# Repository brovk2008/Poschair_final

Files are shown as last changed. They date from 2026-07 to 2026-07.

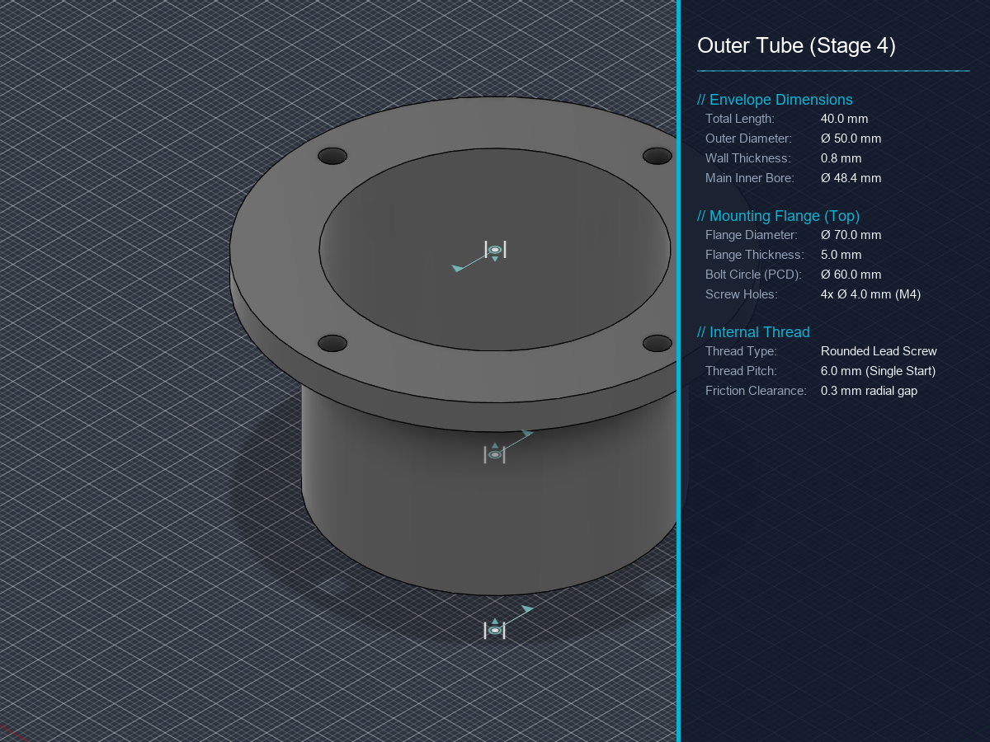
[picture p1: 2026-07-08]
new actuator (tube actuator)/dimentions/OuterTube_dimensions.png

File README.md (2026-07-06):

# PosChair

AI-assisted posture correction hardware for chairs, built around a browser vision loop, BLE control, and a 2x3 paraspinal actuator grid.





PosChair tracks posture locally with MediaPipe Pose, converts posture deviation into six linear actuator targets, and sends those commands to an ESP32 DevKit V1 over Bluetooth Low Energy. The v3 hardware uses DC geared motors, BTS7960 H-bridge drivers, and custom worm-rack actuators that move foam pads up to 100mm.

## Current Version

**V3 motorized actuator architecture**

- 6 custom worm-rack actuators in a 2x3 paraspinal grid
- 6 BTS7960 H-bridge motor drivers
- ESP32 DevKit V1 BLE peripheral using NimBLE-Arduino
- Web Bluetooth dashboard for Chrome/Edge
- Local-only camera posture analysis with MediaPipe WASM
- FastAPI backend for profile, calibration, and session history

## Architecture

```text
Camera
  -> MediaPipe Pose running in browser
  -> Posture analyzer
  -> Velocity-aware decision engine
  -> Web Bluetooth command packet
  -> ESP32 DevKit V1
  -> 6x BTS7960 H-bridges
  -> DC geared motors
  -> Worm-rack actuators
  -> Foam pads on paraspinal muscles
```

## Hardware Layout

```text
        LEFT COLUMN      RIGHT COLUMN

ROW 1:  [UL - M0]       [UR - M1]    Upper thoracic / shoulder
ROW 2:  [ML - M2]       [MR - M3]    Mid lumbar
ROW 3:  [LL - M4]       [LR - M5]    Lower lumbar / pelvis
```

The center spine line is intentionally left open. The modules press into paraspinal muscle areas on either side of the spine.

## Features

- **Position-based actuation:** command values are 0-100, mapping to 0-100mm of linear pad travel.
- **Continuous correction:** forward lean and lateral lean are mapped proportionally instead of using only fixed thresholds.
- **Velocity awareness:** fast posture deterioration increases actuator response before the user fully slouches.
- **Confidence gating:** low-confidence pose frames hold the previous motor target to avoid mechanical jitter.
- **Startup homing:** every boot retracts the actuators to the 0mm home position before BLE control begins.
- **BLE failsafe:** if command packets stop for more than 2 seconds, all modules retract to 0mm.
- **Privacy-first vision:** raw camera frames stay in the browser.

## Repository Structure

```text
firmware/
  poschair_firmware/      Main ESP32 DevKit BLE + motor control firmware
  poschair_motor_test/    Motor calibration and wiring test sketch

app/
  frontend/               React + Vite dashboard with Web Bluetooth
  backend/                FastAPI backend for profiles, calibration, sessions
  docker-compose.yml      Local full-stack development environment

docs/
  hardware_wiring.md      BTS7960, ESP32 DevKit, and actuator wiring reference
  protocol.md             BLE packet protocol reference

website/                  Public Next.js marketing/documentation site
```

## Quick Start

### 1. Wire the Hardware

Connect each BTS7960 driver to the ESP32 DevKit V1 using the pin map in [docs/hardware_wiring.md](docs/hardware_wiring.md). Use a separate motor power rail sized for your motors and keep all grounds common.

Do not power the DC motors from the ESP32 or USB.

### 2. Calibrate Motor Speed

Flash the motor test sketch:

```text
firmware/poschair_motor_test/poschair_motor_test.ino
```

Measure how far each actuator moves during the 2000ms extension test.

```text
MOTOR_SPEED_MM_PER_MS = measured_mm / 2000.0
```

Update the value in:

```text
firmware/poschair_firmware/config.h
```

### 3. Flash Main Firmware

Open the main sketch in Arduino IDE 2.x:

```text
firmware/poschair_firmware/poschair_firmware.ino
```

Recommended Arduino settings:

- Board: `ESP32 Dev Module`
- Flash Size: `4MB`
- CPU Frequency: `240MHz`
- Library: `NimBLE-Arduino`

### 4. Run the App

```bash
cd app
docker-compose up --build
```

Open [http://localhost:5173](http://localhost:5173) in Chrome or Edge.

Web Bluetooth is required, so Safari/iOS and Firefox are not supported for hardware control.

## BLE Protocol

Device name:

```text
POSCHAIR_001
```

Command packet, app to ESP32:

```text
[0]   0xA5
[1]   UL position 0-100
[2]   UR position 0-100
[3]   ML position 0-100
[4]   MR position 0-100
[5]   LL position 0-100
[6]   LR position 0-100
[7]   XOR checksum of bytes 0-6
```

Status packet, ESP32 to app:

```text
[0]   0x5A
[1]   flags: bit0=ok, bit1=failsafe, bit2=homed, bit3=moving
[2]   battery mV high byte
[3]   battery mV low byte
[4-9] current module positions, UL through LR
```

See [docs/protocol.md](docs/protocol.md) for UUIDs and test packets.

## Development Commands

Frontend dashboard:

```bash
cd app/frontend
npm run build
```

Website:

```bash
cd website
npm run build
```

Full local stack:

```bash
cd app
docker-compose up --build
```

## Safety Notes

This project controls physical hardware. Use conservative travel limits, soft foam padding, current-appropriate wiring, and a separate motor power supply. Test one module at a time before wearing or leaning against the full chair attachment.

The firmware clamps commanded travel to 100mm and retracts on BLE timeout, but mechanical end stops and careful power design are still required.

## Status

V3 implementation is active on ESP32 DevKit V1. The app and website builds pass locally. Firmware should be compiled and flashed through Arduino IDE after installing NimBLE-Arduino and selecting the ESP32 board package.

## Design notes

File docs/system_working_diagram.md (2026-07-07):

# PosChair V3 System Working Diagram

This document shows the full PosChair V3 system from every user, sensor, software, BLE, firmware, driver, motor, actuator, and feedback input to every output.

## 1. End-to-End System Flow

```mermaid
flowchart LR
  User["User sitting on chair"]
  Camera["Browser camera input"]
  Light["Lighting / camera angle"]
  Browser["Chrome or Edge dashboard"]
  Pose["MediaPipe Pose WASM"]
  Analyzer["Posture Analyzer"]
  Decision["V3 Decision Engine"]
  BLEClient["Web Bluetooth Manager"]
  BLEAir["BLE radio link"]
  ESP32["ESP32 DevKit V1 firmware"]
  MotorCtrl["MotorController timed-position model"]
  Drivers["6x BTS7960 H-bridge drivers"]
  Motors["6x DC geared motors"]
  WormRack["6x worm-rack actuators"]
  FoamPads["6x foam pads"]
  Back["User paraspinal muscles"]
  Status["BLE status notify"]
  UI["Dashboard UI"]
  Backend["FastAPI backend"]
  DB["PostgreSQL database"]

  User --> Camera
  Light --> Camera
  Camera --> Browser
  Browser --> Pose
  Pose --> Analyzer
  Analyzer --> Decision
  Decision --> BLEClient
  BLEClient --> BLEAir
  BLEAir --> ESP32
  ESP32 --> MotorCtrl
  MotorCtrl --> Drivers
  Drivers --> Motors
  Motors --> WormRack
  WormRack --> FoamPads
  FoamPads --> Back
  Back --> User

  ESP32 --> Status
  Status --> BLEAir
  BLEAir --> BLEClient
  BLEClient --> UI
  Analyzer --> UI
  Decision --> UI
  UI --> Backend
  Backend --> DB
  DB --> Backend
  Backend --> UI
```

## 1A. Physical Wiring Connection Diagram

```mermaid
flowchart LR
  ESP["ESP32 DevKit V1"]
  GND["Common ground bus"]
  V33["ESP32 3.3V"]
  EN["GPIO5 shared enable"]
  ADC["GPIO34 battery ADC"]
  BATP["12V battery positive"]
  BATN["12V battery negative"]
  Fuse["Fuse / switch"]
  Divider["100k / 100k voltage divider"]

  subgraph Drivers["BTS7960 drivers"]
    D0["M0 UL driver"]
    D1["M1 UR driver"]
    D2["M2 ML driver"]
    D3["M3 MR driver"]
    D4["M4 LL driver"]
    D5["M5 LR driver"]
  end

  subgraph Motors["DC motors and actuators"]
    M0["M0 upper-left motor"]
    M1["M1 upper-right motor"]
    M2["M2 mid-left motor"]
    M3["M3 mid-right motor"]
    M4["M4 lower-left motor"]
    M5["M5 lower-right motor"]
  end

  ESP -->|"GPIO25 RPWM, GPIO26 LPWM"| D0
  ESP -->|"GPIO27 RPWM, GPIO16 LPWM"| D1
  ESP -->|"GPIO14 RPWM, GPIO13 LPWM"| D2
  ESP -->|"GPIO17 RPWM, GPIO18 LPWM"| D3
  ESP -->|"GPIO21 RPWM, GPIO22 LPWM"| D4
  ESP -->|"GPIO23 RPWM, GPIO19 LPWM"| D5

  EN -->|"R_EN + L_EN"| D0
  EN -->|"R_EN + L_EN"| D1
  EN -->|"R_EN + L_EN"| D2
  EN -->|"R_EN + L_EN"| D3
  EN -->|"R_EN + L_EN"| D4
  EN -->|"R_EN + L_EN"| D5

  V33 -->|"VCC logic"| D0
  V33 -->|"VCC logic"| D1
  V33 -->|"VCC logic"| D2
  V33 -->|"VCC logic"| D3
  V33 -->|"VCC logic"| D4
  V33 -->|"VCC logic"| D5

  BATP --> Fuse
  Fuse -->|"B+"| D0
  Fuse -->|"B+"| D1
  Fuse -->|"B+"| D2
  Fuse -->|"B+"| D3
  Fuse -->|"B+"| D4
  Fuse -->|"B+"| D5

  BATN --> GND
  ESP -->|"GND"| GND
  GND -->|"GND and B-"| D0
  GND -->|"GND and B-"| D1
  GND -->|"GND and B-"| D2
  GND -->|"GND and B-"| D3
  GND -->|"GND and B-"| D4
  GND -->|"GND and B-"| D5

  D0 -->|"M+ / M-"| M0
  D1 -->|"M+ / M-"| M1
  D2 -->|"M+ / M-"| M2
  D3 -->|"M+ / M-"| M3
  D4 -->|"M+ / M-"| M4
  D5 -->|"M+ / M-"| M5

  BATP --> Divider
  GND --> Divider
  Divider --> ADC
```

## 1B. One Driver Wiring Template

```mermaid
flowchart TB
  ESP["ESP32 DevKit"]
  Driver["One BTS7960 driver"]
  Motor["One DC geared motor"]
  Battery["12V motor supply"]
  Ground["Common ground"]

  ESP -->|"Assigned RPWM GPIO"| Driver
  ESP -->|"Assigned LPWM GPIO"| Driver
  ESP -->|"GPIO5 to R_EN"| Driver
  ESP -->|"GPIO5 to L_EN"| Driver
  ESP -->|"3.3V to VCC"| Driver
  ESP -->|"GND"| Ground
  Ground -->|"GND and B-"| Driver
  Battery -->|"B+"| Driver
  Driver -->|"M+"| Motor
  Driver -->|"M-"| Motor
```

## 2. Inputs and Outputs

```mermaid
flowchart TB
  subgraph Inputs["Inputs"]
    CameraFrames["Camera frames"]
    UserMode["Mode selection: office / gaming / study / relax"]
    Calibration["Calibration baseline"]
    ManualOverride["Manual position sliders"]
    BLEStatusIn["ESP32 status notifications"]
    BatterySense["Battery voltage divider on GPIO34"]
    MotorSpeedCal["MOTOR_SPEED_MM_PER_MS calibration"]
    PowerOn["Power-on / reset"]
    BLEDisconnect["BLE disconnect or silent packets"]
  end

  subgraph Processing["Processing"]
    PoseDetection["Pose landmark detection"]
    ConfidenceGate["Confidence gate >= 0.65"]
    Geometry["Spine, lateral, head-offset geometry"]
    Velocity["Spine and lateral velocity calculation"]
    PositionMapping["0-100mm target mapping"]
    PacketBuild["8-byte BLE command packet"]
    PacketParse["ESP32 checksum validation"]
    BatteryRead["Battery ADC reading"]
    TimedMotion["Timed motor run duration"]
    Homing["Startup homing to 0mm"]
    Failsafe["2-second BLE failsafe"]
  end

  subgraph Outputs["Outputs"]
    TargetPositions["Target positions: UL UR ML MR LL LR"]
    Dashboard["Live dashboard state"]
    BLEPacket["BLE write without response"]
    PWMOut["RPWM / LPWM PWM output"]
    MotorMotion["Motor extend / retract / brake / coast"]
    PadTravel["Foam pad travel: 0-100mm"]
    SessionLogs["Session analytics logs"]
    SafetyRetract["All modules retract to 0mm"]
  end

  CameraFrames --> PoseDetection
  PoseDetection --> ConfidenceGate
  ConfidenceGate --> Geometry
  Geometry --> Velocity
  Velocity --> PositionMapping
  UserMode --> PositionMapping
  Calibration --> Geometry
  ManualOverride --> TargetPositions
  PositionMapping --> TargetPositions
  TargetPositions --> PacketBuild
  PacketBuild --> BLEPacket
  BLEPacket --> PacketParse
  PacketParse --> TimedMotion
  MotorSpeedCal --> TimedMotion
  BatterySense --> BatteryRead
  BatteryRead --> Dashboard
  TimedMotion --> PWMOut
  PWMOut --> MotorMotion
  MotorMotion --> PadTravel
  BLEStatusIn --> Dashboard
  Geometry --> Dashboard
  PositionMapping --> Dashboard
  Dashboard --> SessionLogs
  PowerOn --> Homing
  Homing --> SafetyRetract
  BLEDisconnect --> Failsafe
  Failsafe --> SafetyRetract
```

## 3. Browser App Processing Loop

```mermaid
flowchart TD
  Start["User clicks Enable Tracking"]
  CameraPermission["Request camera permission"]
  LoadModel["Load MediaPipe Pose Landmarker"]
  FrameLoop["requestAnimationFrame loop"]
  Detect["Detect 33 pose landmarks"]
  HasLandmarks{"Landmarks found?"}
  Analyze["Analyze posture geometry"]
  ComputeVelocity["Compute velocity deg/sec"]
  Confidence{"Confidence >= 0.65?"}
  Hold["Hold previous target positions"]
  ComputeTargets["Compute V3 target positions"]
  Hysteresis["Apply 3-unit hysteresis"]
  UpdateUI["Update score, confidence, velocity, grid UI"]
  SendAllowed{"BLE connected and Active BLE Loop?"}
  Throttle{"100ms send interval elapsed?"}
  SendBLE["Send 8-byte position packet"]
  LogScore{"1s score log interval?"}
  SaveHistory["Append score to session history"]
  NextFrame["Next animation frame"]

  Start --> CameraPermission
  CameraPermission --> LoadModel
  LoadModel --> FrameLoop
  FrameLoop --> Detect
  Detect --> HasLandmarks
  HasLandmarks -- "No" --> NextFrame
  HasLandmarks -- "Yes" --> Analyze
  Analyze --> ComputeVelocity
  ComputeVelocity --> Confidence
  Confidence -- "No" --> Hold
  Confidence -- "Yes" --> ComputeTargets
  ComputeTargets --> Hysteresis
  Hold --> UpdateUI
  Hysteresis --> UpdateUI
  UpdateUI --> SendAllowed
  SendAllowed -- "No" --> LogScore
  SendAllowed -- "Yes" --> Throttle
  Throttle -- "No" --> LogScore
  Throttle -- "Yes" --> SendBLE
  SendBLE --> LogScore
  LogScore -- "Yes" --> SaveHistory
  LogScore -- "No" --> NextFrame
  SaveHistory --> NextFrame
  NextFrame --> FrameLoop
```

## 4. Decision Engine Mapping

```mermaid
flowchart LR
  SpineDeviation["spineDeviation or spineAngleDeg"]
  LateralDeviation["lateralDeviation or lateralLeanDeg"]
  SpineVelocity["velocitySpine"]
  Mode["Mode scale"]
  Confidence["confidence"]

  Gate{"confidence < 0.65?"}
  Prev["Return previous positions"]
  ForwardMap["Forward proportional map"]
  VelocityBonus["Velocity anticipation bonus"]
  LateralSplit["Lateral opposite-column boost"]
  Scale["Apply mode scale"]
  Clamp["Clamp each value 0-100"]
  Hysteresis["Only change if delta >= 3"]
  Positions["[UL, UR, ML, MR, LL, LR] positions"]

  Confidence --> Gate
  Gate -- "Yes" --> Prev
  Prev --> Positions
  Gate -- "No" --> ForwardMap
  SpineDeviation --> ForwardMap
  SpineVelocity --> VelocityBonus
  VelocityBonus --> ForwardMap
  LateralDeviation --> LateralSplit
  ForwardMap --> Scale
  LateralSplit --> Scale
  Mode --> Scale
  Scale --> Clamp
  Clamp --> Hysteresis
  Hysteresis --> Positions
```

## 5. BLE Packet Path

```mermaid
sequenceDiagram
  participant App as Browser App
  participant BLE as Web Bluetooth
  participant ESP as ESP32 DevKit NimBLE
  participant FW as Firmware Parser
  participant MC as MotorController
  participant UI as Dashboard UI

  App->>App: Clamp positions to 0-100
  App->>App: Build 8-byte packet
  Note over App: A5 UL UR ML MR LL LR XOR
  App->>BLE: writeValueWithoutResponse(command)
  BLE->>ESP: Command characteristic write
  ESP->>FW: onWrite callback
  FW->>FW: Validate length, header, checksum
  alt Valid packet
    FW->>MC: setTarget(i, position)
    FW->>FW: lastValidPacketMs = millis()
  else Invalid packet
    FW-->>ESP: Drop packet
  end
  ESP->>ESP: Every 1000ms build status
  Note over ESP: 5A flags battery_mV UL UR ML MR LL LR
  ESP->>BLE: notify(status)
  BLE->>App: characteristicvaluechanged
  App->>UI: Update homed, moving, failsafe, actual positions
```

## 6. ESP32 Firmware Loop

```mermaid
flowchart TD
  Boot["Power-on / reset"]
  InitSerial["Start Serial"]
  InitMotorPins["Attach RPWM and LPWM PWM pins"]
  EnableDrivers["Set shared EN_PIN HIGH"]
  HomeAll["Run all motors inward for HOMING_TIMEOUT_MS"]
  ZeroPositions["Set current positions to 0"]
  StartBLE["Advertise as POSCHAIR_001"]
  Loop["Main loop"]
  UpdateMotors["MotorController.update"]
  Timeout{"No valid BLE packet > 2000ms?"}
  EnterFailsafe["Set failsafe active"]
  RetractAll["Command all targets to 0mm"]
  StatusDue{"Status interval elapsed?"}
  Notify["Notify 10-byte status packet"]
  Continue["Continue loop"]

  Boot --> InitSerial
  InitSerial --> InitMotorPins
  InitMotorPins --> EnableDrivers
  EnableDrivers --> HomeAll
  HomeAll --> ZeroPositions
  ZeroPositions --> StartBLE
  StartBLE --> Loop
  Loop --> UpdateMotors
  UpdateMotors --> Timeout
  Timeout -- "Yes" --> EnterFailsafe
  EnterFailsafe --> RetractAll
  RetractAll --> StatusDue
  Timeout -- "No" --> StatusDue
  StatusDue -- "Yes" --> Notify
  StatusDue -- "No" --> Continue
  Notify --> Continue
  Continue --> Loop
```

## 7. Single Module Motor Control

```mermaid
stateDiagram-v2
  [*] --> IDLE
  IDLE --> MOVING_OUT: target > current
  IDLE --> MOVING_IN: target < current
  MOVING_OUT --> IDLE: run duration elapsed
  MOVING_IN --> IDLE: run duration elapsed
  IDLE --> HOMING: startup
  HOMING --> IDLE: timeout complete and position zeroed
  MOVING_OUT --> MOVING_IN: new lower target
  MOVING_IN --> MOVING_OUT: new higher target
  MOVING_OUT --> IDLE: stopAll
  MOVING_IN --> IDLE: stopAll
```

```mermaid
flowchart LR
  Target["Target position 0-100mm"]
  Current["Current estimated position"]
  Delta["delta_mm = abs(target - current)"]
  Speed["MOTOR_SPEED_MM_PER_MS"]
  Duration["duration_ms = delta_mm / speed"]
  Direction{"target > current?"}
  Out["Extend: RPWM=200 LPWM=0"]
  In["Retract: RPWM=0 LPWM=200"]
  Stop["Stop: RPWM=0 LPWM=0"]
  Update["Set current = target"]

  Target --> Delta
  Current --> Delta
  Delta --> Duration
  Speed --> Duration
  Duration --> Direction
  Direction -- "Yes" --> Out
  Direction -- "No" --> In
  Out --> Stop
  In --> Stop
  Stop --> Update
```

## 8. Physical Output Grid

```mermaid
flowchart TB
  subgraph Grid["2x3 Paraspinal Actuator Grid"]
    UL["M0 UL: Upper-Left foam pad"]
    UR["M1 UR: Upper-Right foam pad"]
    ML["M2 ML: Mid-Left foam pad"]
    MR["M3 MR: Mid-Right foam pad"]
    LL["M4 LL: Lower-Left foam pad"]
    LR["M5 LR: Lower-Right foam pad"]
  end

  subgraph Anatomy["User Back Contact Zones"]
    ULeft["Upper-left paraspinal zone"]
    URight["Upper-right paraspinal zone"]
    MLeft["Mid-left lumbar zone"]
    MRight["Mid-right lumbar zone"]
    LLeft["Lower-left pelvis/lumbar zone"]
    LRight["Lower-right pelvis/lumbar zone"]
    SpineGap["2cm open spine gap"]
  end

  UL --> ULeft
  UR --> URight
  ML --> MLeft
  MR --> MRight
  LL --> LLeft
  LR --> LRight
  ULeft --- SpineGap
  MLeft --- SpineGap
  LLeft --- SpineGap
  SpineGap --- URight
  SpineGap --- MRight
  SpineGap --- LRight
```

## 9. Safety and Failure Paths

```mermaid
flowchart TD
  Normal["Normal closed-loop operation"]
  BadPacket["Bad BLE packet"]
  LowConfidence["Low pose confidence"]
  BLETimeout["No valid BLE command for 2s"]
  PowerCycle["Power cycle / reset"]
  ManualStop["User stops camera or disconnects"]

  Drop["Drop packet, keep previous target"]
  Hold["Hold previous positions"]
  Retract["Retract all modules to 0mm"]
  Home["Startup homing to 0mm"]
  UIWarn["Show UI warning or disconnected state"]
  SafeState["Safe mechanical state"]

  Normal --> BadPacket
  Normal --> LowConfidence
  Normal --> BLETimeout
  Normal --> PowerCycle
  Normal --> ManualStop

  BadPacket --> Drop
  Drop --> SafeState
  LowConfidence --> Hold
  Hold --> SafeState
  BLETimeout --> Retract
  Retract --> SafeState
  PowerCycle --> Home
  Home --> SafeState
  ManualStop --> UIWarn
  UIWarn --> SafeState
```

## 10. Backend Data Flow

```mermaid
flowchart LR
  UI["React dashboard"]
  Profile["Profile form / default user"]
  CalibrationModal["Calibration modal"]
  Session["Monitoring session"]
  API["FastAPI backend"]
  DB["PostgreSQL"]
  Analytics["Analytics dashboard"]

  Profile --> UI
  CalibrationModal --> UI
  Session --> UI
  UI -->|POST /profile| API
  UI -->|POST /calibration| API
  UI -->|POST /sessions| API
  UI -->|GET /sessions/:userId| API
  API --> DB
  DB --> API
  API --> Analytics
  Analytics --> UI
```

## 11. Key Signals and Units

| Signal | Source | Destination | Unit / Format |
|---|---|---|---|
| Camera frames | Browser camera | MediaPipe Pose | Video frame |
| Pose landmarks | MediaPipe Pose | Posture analyzer | 33 landmarks |
| `spineAngleDeg` | Posture analyzer | Decision engine / UI | Degrees |
| `lateralLeanDeg` | Posture analyzer | Decision engine / UI | Degrees |
| `velocitySpine` | Posture analyzer | Decision engine / UI | Degrees per second |
| `confidence` | Pose landmarks | Decision engine / UI | 0.0-1.0 |
| Target positions | Decision engine | BLE manager | 6 values, 0-100mm |
| Command packet | BLE manager | ESP32 DevKit V1 | 8 bytes |
| Battery voltage | ESP32 DevKit V1 ADC | Dashboard status packet | Millivolts |
| Current positions | ESP32 DevKit V1 | Dashboard UI | 6 values, 0-100mm |
| Motor PWM | ESP32 DevKit V1 | BTS7960 drivers | 0-255 duty |
| Foam pad travel | Worm-rack actuator | User back | 0-100mm |

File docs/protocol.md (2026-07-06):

# PosChair BLE Protocol Specification (V3)

This document defines the binary BLE protocol between the browser app and the ESP32 DevKit V1 motor controller.

## Device Information

- **BLE Device Local Name:** `POSCHAIR_001`
- **Service UUID:** `a1b2c3d4-0001-4b5c-8d6e-1f2a3b4c5d6e`
- **Command Characteristic:** `a1b2c3d4-0002-4b5c-8d6e-1f2a3b4c5d6e`
- **Status Characteristic:** `a1b2c3d4-0003-4b5c-8d6e-1f2a3b4c5d6e`

## Module Order

```text
0 = Upper-Left   (UL)
1 = Upper-Right  (UR)
2 = Mid-Left     (ML)
3 = Mid-Right    (MR)
4 = Lower-Left   (LL)
5 = Lower-Right  (LR)
```

All command and status arrays use this exact order.

## Command Packet

App to ESP32, 8 bytes, write without response. Position units are millimeters.

| Byte | Field | Type | Description |
|---|---|---|---|
| 0 | Header | `uint8_t` | Constant `0xA5` |
| 1 | UL position | `uint8_t` | 0-100 = 0-100mm |
| 2 | UR position | `uint8_t` | 0-100 = 0-100mm |
| 3 | ML position | `uint8_t` | 0-100 = 0-100mm |
| 4 | MR position | `uint8_t` | 0-100 = 0-100mm |
| 5 | LL position | `uint8_t` | 0-100 = 0-100mm |
| 6 | LR position | `uint8_t` | 0-100 = 0-100mm |
| 7 | Checksum | `uint8_t` | XOR of bytes 0-6 |

```text
checksum = B0 ^ B1 ^ B2 ^ B3 ^ B4 ^ B5 ^ B6
```

## Status Packet

ESP32 to app, 10 bytes, notify about once per second.

| Byte | Field | Type | Description |
|---|---|---|---|
| 0 | Header | `uint8_t` | Constant `0x5A` |
| 1 | Flags | `uint8_t` | bit0=ok, bit1=failsafe, bit2=homed, bit3=any motor moving |
| 2 | Battery voltage MSB | `uint8_t` | Big-endian millivolts |
| 3 | Battery voltage LSB | `uint8_t` | Big-endian millivolts |
| 4 | UL current position | `uint8_t` | 0-100mm |
| 5 | UR current position | `uint8_t` | 0-100mm |
| 6 | ML current position | `uint8_t` | 0-100mm |
| 7 | MR current position | `uint8_t` | 0-100mm |
| 8 | LL current position | `uint8_t` | 0-100mm |
| 9 | LR current position | `uint8_t` | 0-100mm |

## Test Packets

```text
All retracted:         A5 00 00 00 00 00 00 A5
ML+MR to 50mm:         A5 00 00 32 32 00 00 E5
Full left column out:  A5 64 00 64 00 64 00 81
All fully extended:    A5 64 64 64 64 64 64 C5
```

## Failsafe

If no valid command packet arrives for more than `FAILSAFE_TIMEOUT_MS` (2000ms), the ESP32 sets the failsafe flag and commands all modules back to 0mm.

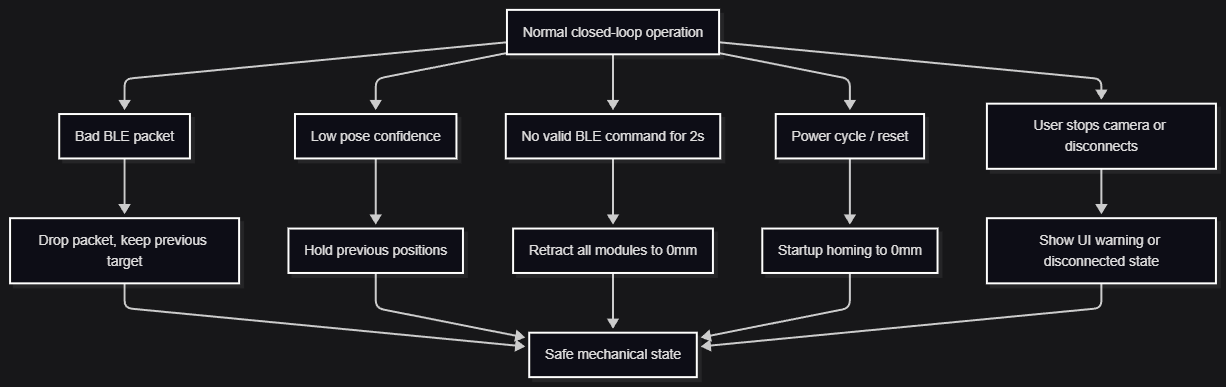
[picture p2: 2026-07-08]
10str.png

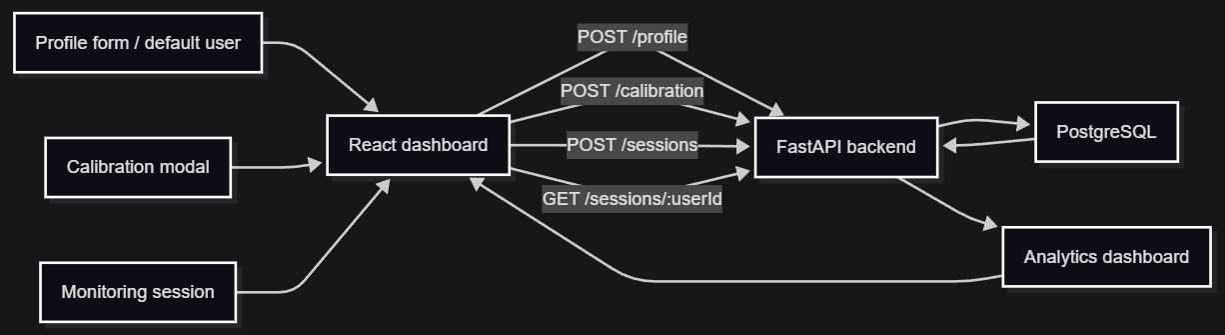
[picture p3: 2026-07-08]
11str.png

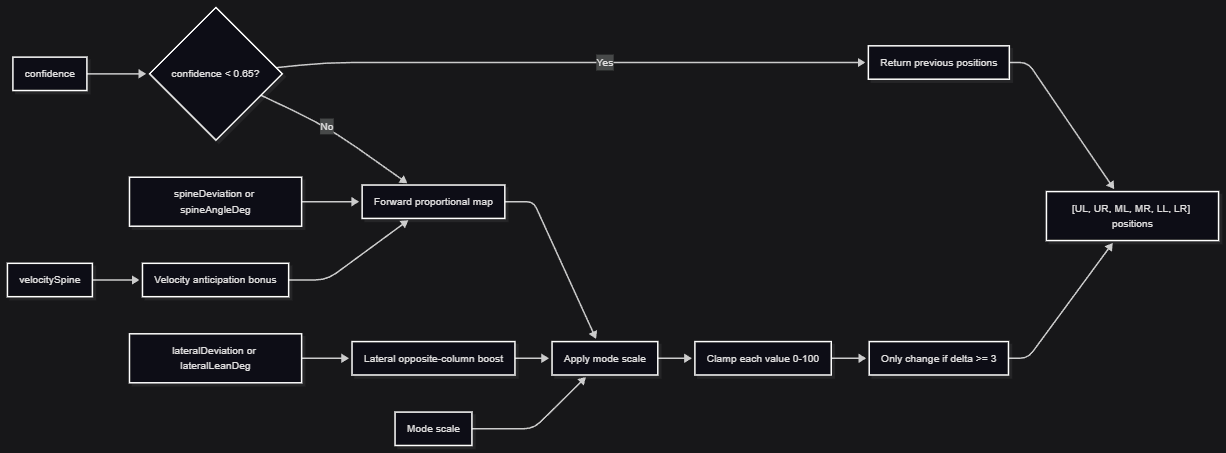
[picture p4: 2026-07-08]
4str.png

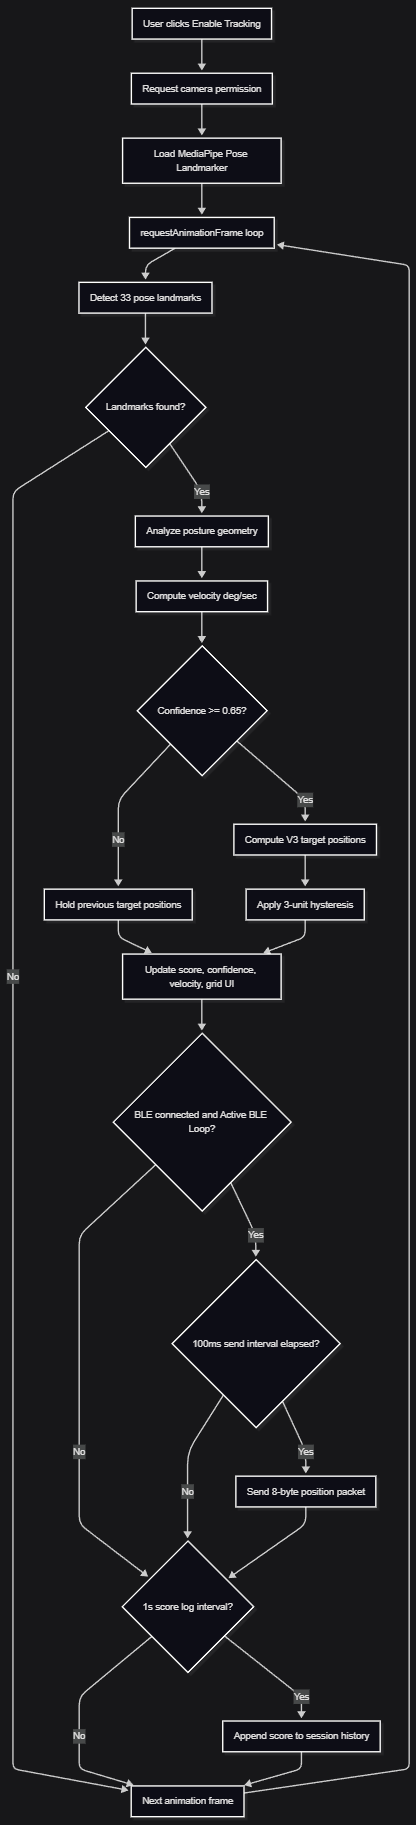
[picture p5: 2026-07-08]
3str.png

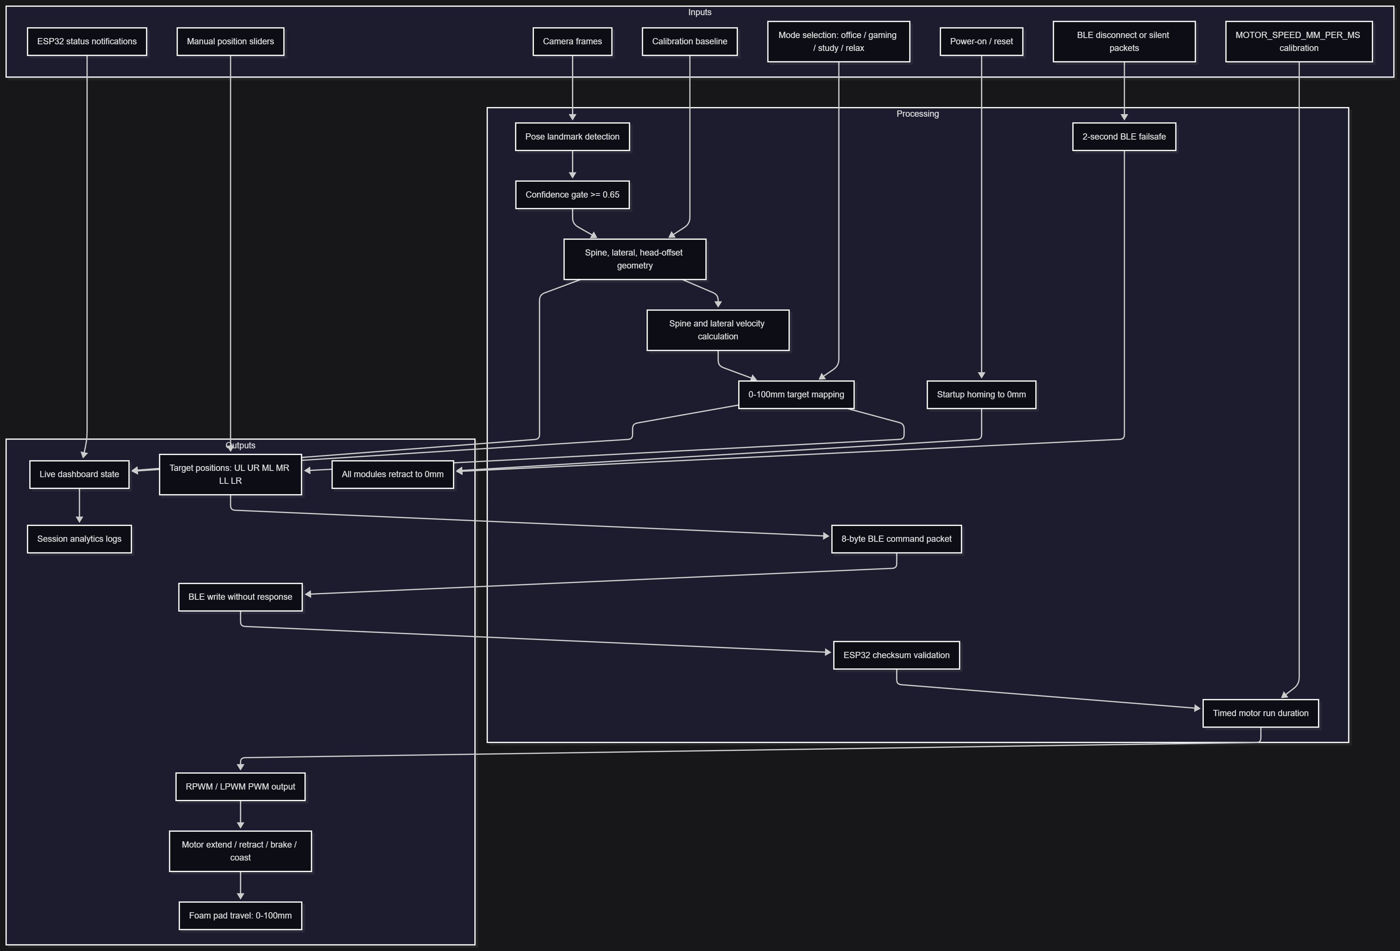
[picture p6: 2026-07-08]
2str.png

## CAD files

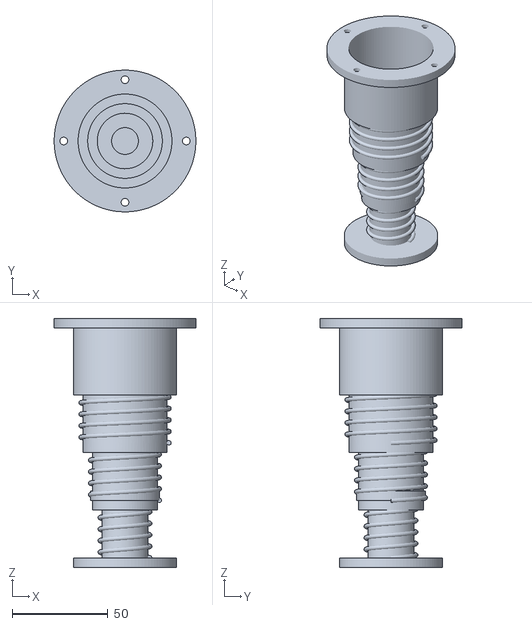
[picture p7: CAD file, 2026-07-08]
new actuator (tube actuator)/TelescopicAssembly_Compressed.obj
74.0 x 74.0 x 130.0

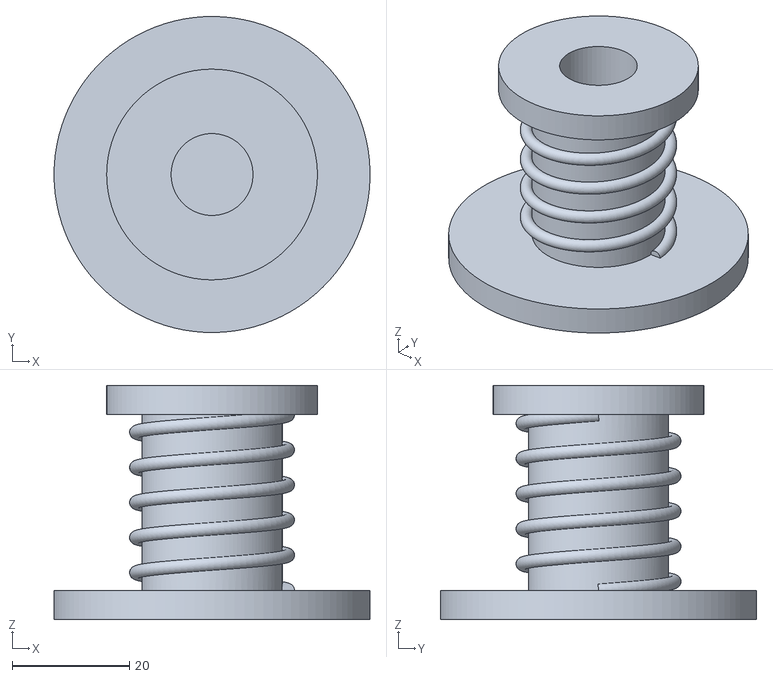
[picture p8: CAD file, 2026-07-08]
new actuator (tube actuator)/InnerTube.stl
54.0 x 54.0 x 40.0

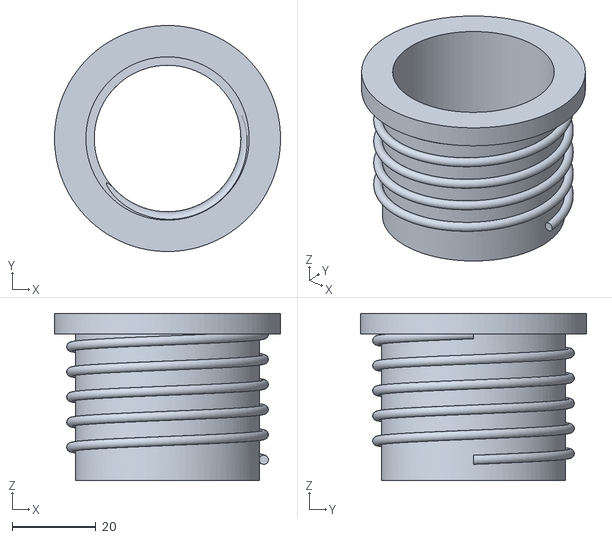
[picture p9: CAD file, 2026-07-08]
new actuator (tube actuator)/Middle2Tube.stl
54.0 x 54.0 x 40.0

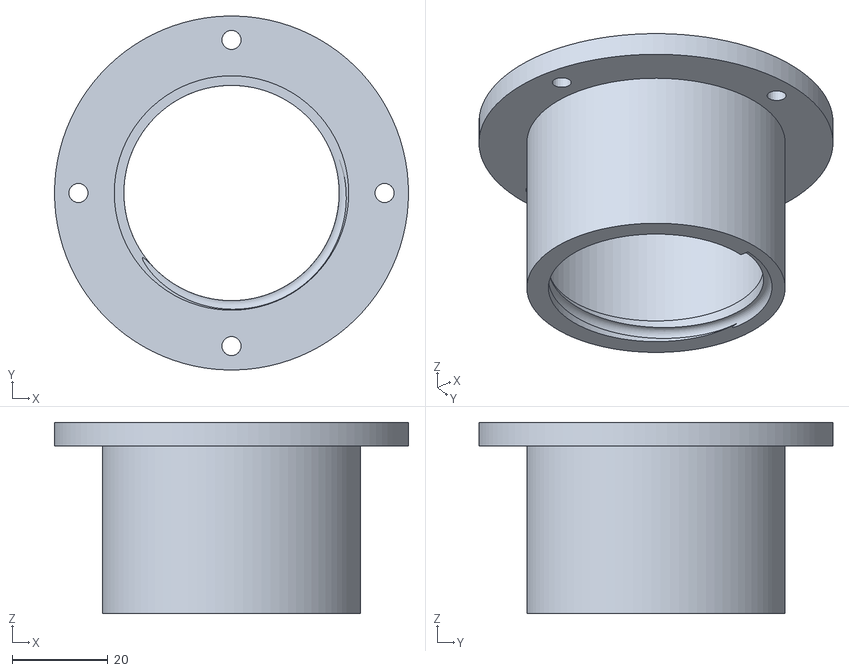
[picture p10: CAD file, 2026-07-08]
new actuator (tube actuator)/OuterTube.stl
74.0 x 74.0 x 40.0

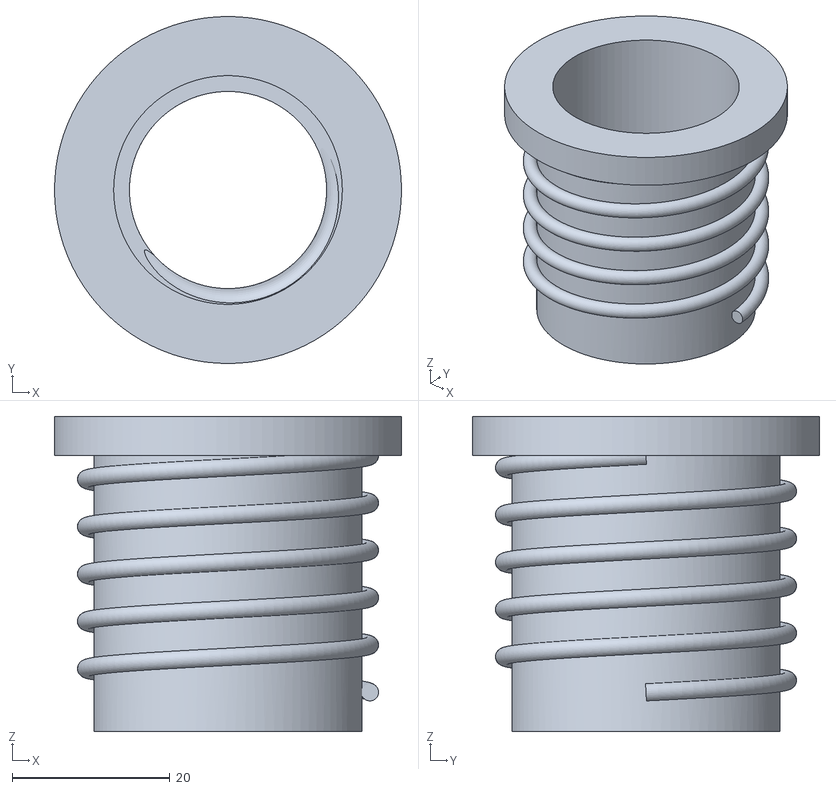
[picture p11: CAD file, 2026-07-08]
new actuator (tube actuator)/Middle1Tube.stl
44.0 x 44.0 x 40.0

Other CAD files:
new actuator (tube actuator)/InnerTube.obj
new actuator (tube actuator)/Middle1Tube.obj
new actuator (tube actuator)/Middle2Tube.obj
new actuator (tube actuator)/OuterTube.obj

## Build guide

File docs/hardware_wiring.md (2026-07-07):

# PosChair V3 Build Wiring Guide

This is the build-facing wiring reference for the ESP32 DevKit V1 version of PosChair V3. Follow this when connecting the ESP32, six BTS7960 motor drivers, six DC geared motors, the 12V motor supply, and the battery voltage divider.

## Read This First

- Do not power motors from the ESP32, USB, or breadboard power rails.
- Use a separate motor supply sized for the stall current of all six motors.
- All grounds must be common: ESP32 GND, BTS7960 GND, motor battery negative, and voltage-divider ground.
- Avoid ESP32 GPIO0, GPIO2, GPIO12, and GPIO15 for motors because they are boot-strapping pins.
- Avoid GPIO6-GPIO11 because they are connected to onboard flash.
- Wire and test one motor module first before connecting all six.

## Parts In This Wiring

| Item | Qty | Notes |
|---|---:|---|
| ESP32 DevKit V1, 38-pin | 1 | Arduino board target: `ESP32 Dev Module` |
| BTS7960 H-bridge driver | 6 | One driver per actuator |
| DC geared motor | 6 | One motor per worm-rack actuator |
| Worm-rack actuator + foam pad | 6 | 0-100mm travel target |
| 12V motor battery / supply | 1 | Motor power rail only |
| 100k resistor | 2 | Battery voltage divider |
| Common ground bus | 1 | Required |
| Inline fuse / switch | 1 recommended | Put on battery positive |

## Physical Grid

```text
        LEFT COLUMN      RIGHT COLUMN

ROW 1:  [M0 UL]         [M1 UR]       Upper thoracic / shoulder
ROW 2:  [M2 ML]         [M3 MR]       Mid lumbar
ROW 3:  [M4 LL]         [M5 LR]       Lower lumbar / pelvis
```

Keep a 2cm open gap between left and right columns. The foam pads should contact paraspinal muscles, not the spine itself.

## Full Connection Map

Label your BTS7960 boards `M0` through `M5` before wiring.

| Module | Body Position | BTS7960 RPWM | BTS7960 LPWM | BTS7960 R_EN | BTS7960 L_EN | Motor Output |
|---|---|---:|---:|---:|---:|---|
| M0 | Upper-Left | ESP32 GPIO25 | ESP32 GPIO26 | ESP32 GPIO5 | ESP32 GPIO5 | M0 motor `M+` / `M-` |
| M1 | Upper-Right | ESP32 GPIO27 | ESP32 GPIO16 | ESP32 GPIO5 | ESP32 GPIO5 | M1 motor `M+` / `M-` |
| M2 | Mid-Left | ESP32 GPIO14 | ESP32 GPIO13 | ESP32 GPIO5 | ESP32 GPIO5 | M2 motor `M+` / `M-` |
| M3 | Mid-Right | ESP32 GPIO17 | ESP32 GPIO18 | ESP32 GPIO5 | ESP32 GPIO5 | M3 motor `M+` / `M-` |
| M4 | Lower-Left | ESP32 GPIO21 | ESP32 GPIO22 | ESP32 GPIO5 | ESP32 GPIO5 | M4 motor `M+` / `M-` |
| M5 | Lower-Right | ESP32 GPIO23 | ESP32 GPIO19 | ESP32 GPIO5 | ESP32 GPIO5 | M5 motor `M+` / `M-` |

## ESP32 Pin Checklist

| ESP32 Pin | Connect To | Purpose |
|---:|---|---|
| GPIO25 | M0 BTS7960 `RPWM` | Upper-left extend PWM |
| GPIO26 | M0 BTS7960 `LPWM` | Upper-left retract PWM |
| GPIO27 | M1 BTS7960 `RPWM` | Upper-right extend PWM |
| GPIO16 | M1 BTS7960 `LPWM` | Upper-right retract PWM |
| GPIO14 | M2 BTS7960 `RPWM` | Mid-left extend PWM |
| GPIO13 | M2 BTS7960 `LPWM` | Mid-left retract PWM |
| GPIO17 | M3 BTS7960 `RPWM` | Mid-right extend PWM |
| GPIO18 | M3 BTS7960 `LPWM` | Mid-right retract PWM |
| GPIO21 | M4 BTS7960 `RPWM` | Lower-left extend PWM |
| GPIO22 | M4 BTS7960 `LPWM` | Lower-left retract PWM |
| GPIO23 | M5 BTS7960 `RPWM` | Lower-right extend PWM |
| GPIO19 | M5 BTS7960 `LPWM` | Lower-right retract PWM |
| GPIO5 | All BTS7960 `R_EN` and `L_EN` | Shared driver enable |
| GPIO34 | Voltage divider midpoint | Battery voltage ADC |
| 3.3V | All BTS7960 `VCC` pins | Logic power |
| GND | Ground bus | Common logic and motor reference |

## BTS7960 Pin Checklist

Repeat this for each of the six BTS7960 boards.

| BTS7960 Pin | Connect To | Notes |
|---|---|---|
| `RPWM` | Assigned ESP32 RPWM GPIO | Motor extends foam pad when active |
| `LPWM` | Assigned ESP32 LPWM GPIO | Motor retracts foam pad when active |
| `R_EN` | ESP32 GPIO5 | Shared enable |
| `L_EN` | ESP32 GPIO5 | Shared enable |
| `VCC` | ESP32 3.3V | Logic only |
| `GND` | Common ground bus | Must share ESP32 and battery ground |
| `B+` | 12V motor supply positive | Put fuse/switch before distribution |
| `B-` | 12V motor supply negative | Same as common ground |
| `M+` | Motor terminal 1 | Swap with `M-` if direction is reversed |
| `M-` | Motor terminal 2 | Swap with `M+` if direction is reversed |

## Motor Direction Rule

Firmware assumes:

```text
RPWM active, LPWM 0  -> actuator extends, foam pushes out
LPWM active, RPWM 0  -> actuator retracts, foam pulls in
```

If a module moves the wrong way during `poschair_motor_test.ino`, do not change code first. Swap that module motor's `M+` and `M-` wires on the BTS7960 output.

## Power Wiring

```text
12V supply positive -> fuse/switch -> split to all BTS7960 B+ terminals
12V supply negative -> ground bus -> all BTS7960 B- terminals
ESP32 GND -----------> same ground bus
All BTS7960 GND -----> same ground bus
ESP32 3.3V ----------> all BTS7960 VCC logic pins
```

Use thicker wire for `B+`, `B-`, `M+`, and `M-` than for ESP32 signal wires.

## Battery Voltage Divider

Use two 100k resistors so the ESP32 ADC sees half of the battery voltage.

```text
Battery + ---- R1 100k ----+---- ESP32 GPIO34
                           |
                           R2 100k
                           |
Ground bus ----------------+
```

Firmware constants:

```cpp
#define BATTERY_ADC_PIN 34
#define BATTERY_ADC_MAX 4095
#define BATTERY_REF_MV 3300
#define BATTERY_DIVIDER 2.0f
```

## Build Order

1. Mount the six actuator modules on the chair frame.
2. Label each motor wire pair as `M0` through `M5`.
3. Label each BTS7960 board as `M0` through `M5`.
4. Wire only the M0 driver and motor first.
5. Connect ESP32 GND to the motor supply ground.
6. Connect M0 `RPWM`, `LPWM`, `R_EN`, `L_EN`, `VCC`, and `GND`.
7. Connect M0 `B+`, `B-`, `M+`, and `M-`.
8. Flash `firmware/poschair_motor_test/poschair_motor_test.ino`.
9. Confirm M0 extends during OUT and retracts during IN.
10. If M0 direction is wrong, swap M0 `M+` and `M-`.
11. Repeat the same process for M1 through M5.
12. After all six pass the motor test, flash `firmware/poschair_firmware/poschair_firmware.ino`.

## First Power-Up Test

Use this sequence before wearing or leaning against the chair:

1. Keep motors disconnected from the user's back.
2. Power ESP32 from USB only.
3. Open Serial Monitor at `115200`.
4. Confirm boot message prints.
5. Power the 12V motor rail.
6. Run the motor test sketch.
7. Confirm every module extends and retracts in the correct physical location.
8. Measure 2000ms travel for each actuator.
9. Calculate `MOTOR_SPEED_MM_PER_MS = measured_mm / 2000.0`.
10. Update `firmware/poschair_firmware/config.h`.
11. Flash the main firmware.
12. Confirm startup homing retracts all modules.

## Arduino IDE Target

- Board: `ESP32 Dev Module`
- CPU Frequency: `240MHz`
- Upload Speed: `921600`
- Flash Size: `4MB`
- Partition Scheme: `Default 4MB with spiffs`
- USB CDC On Boot: not applicable on DevKit V1

If upload fails, hold the BOOT button while starting upload and release it after `Connecting...` appears.

## Quick Troubleshooting

| Symptom | Likely Cause | Fix |
|---|---|---|
| ESP32 resets when motors move | Motor power sag or shared weak supply | Use stronger 12V supply and common ground |
| Motor does not move | EN not HIGH, no motor power, wrong driver pin | Check GPIO5 to R_EN/L_EN and B+/B- |
| Motor moves backward | Motor output polarity reversed | Swap `M+` and `M-` on that driver |
| Only one direction works | RPWM/LPWM swapped or loose wire | Recheck assigned GPIO and BTS7960 pin |
| BLE works but motors do nothing | Driver enable/power missing | Check GPIO5, VCC, GND, B+ and B- |
| Battery reading is wrong | Divider values or ground wrong | Use two equal resistors and common ground |
| Upload fails | DevKit boot mode issue | Hold BOOT until upload starts |

## Final Safety Check

- All `B-` and ESP32 `GND` points share a common ground.
- No motor current flows through the ESP32 board.
- Every motor can retract before testing extension.
- Foam pads have soft edges and mechanical travel limits.
- The first full test is done without a person leaning on the chair.

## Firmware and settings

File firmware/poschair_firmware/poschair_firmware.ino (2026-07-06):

// PosChair Firmware v3 - ESP32 DevKit V1
// 6 custom worm-rack actuators in 2x3 paraspinal grid.
// Drivers: 6x BTS7960 H-bridges, one DC geared motor per module.
//
// Board: ESP32 Dev Module
// CPU Frequency: 240MHz
// Library: NimBLE-Arduino

#include "config.h"
#include "protocol.h"
#include "motor_controller.h"
#include "ble_manager.h"

MotorController motors;
unsigned long lastStatusMs = 0;
bool failsafeActive = false;

uint16_t readBatteryMv() {
  int raw = analogRead(BATTERY_ADC_PIN);
  return (uint16_t)((raw / (float)BATTERY_ADC_MAX) * BATTERY_REF_MV * BATTERY_DIVIDER);
}

void setup() {
  Serial.begin(115200);
  delay(200);
  Serial.println("\n=== PosChair v3 Firmware Starting ===");
  Serial.println("Layout: UL=M0 UR=M1 ML=M2 MR=M3 LL=M4 LR=M5");
  Serial.println("Actuator: BTS7960 + DC motor + worm-rack timed position control");

  motors.begin();
  motors.homeAll();
  bleManager.begin(&motors);

  Serial.println("Ready. Positions are 0-100mm. Advertising as " BLE_DEVICE_NAME ".");
}

void loop() {
  motors.update();

  const bool timedOut = (millis() - bleManager.lastValidPacketMs() > FAILSAFE_TIMEOUT_MS);
  if (timedOut && !failsafeActive) {
    Serial.println("WARNING: BLE timeout - retracting all modules to 0mm");
    failsafeActive = true;
    for (int i = 0; i < NUM_MODULES; i++) motors.setTarget(i, 0);
  }
  if (!timedOut) failsafeActive = false;

  if (millis() - lastStatusMs > STATUS_INTERVAL_MS) {
    lastStatusMs = millis();
    const uint16_t batteryMv = readBatteryMv();
    bleManager.sendStatus(failsafeActive, batteryMv);

    Serial.printf("[Status] UL=%d UR=%d ML=%d MR=%d LL=%d LR=%d bat=%dmV homed=%d moving=%d fs=%d\n",
      motors.getCurrentPosition(0), motors.getCurrentPosition(1),
      motors.getCurrentPosition(2), motors.getCurrentPosition(3),
      motors.getCurrentPosition(4), motors.getCurrentPosition(5),
      batteryMv, motors.isHomingComplete(), motors.isAnyMoving(), failsafeActive);
  }
}

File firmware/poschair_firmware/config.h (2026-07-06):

#pragma once
#include <Arduino.h>

// Module index map:
// 0=Upper-Left, 1=Upper-Right, 2=Mid-Left, 3=Mid-Right, 4=Lower-Left, 5=Lower-Right
#define NUM_MODULES 6

// BTS7960 PWM pin assignments for ESP32 DevKit V1 (38-pin).
// Avoid GPIO0, GPIO2, GPIO12, and GPIO15 because they are boot-strapping pins.
// Avoid GPIO6-GPIO11 because they are connected to the onboard flash chip.
// RPWM drives rack out, LPWM drives rack in.
const uint8_t RPWM_PINS[NUM_MODULES] = {25, 27, 14, 17, 21, 23};
const uint8_t LPWM_PINS[NUM_MODULES] = {26, 16, 13, 18, 22, 19};

// Shared enable pin. Tie all BTS7960 R_EN and L_EN pins here, HIGH = enabled.
#define EN_PIN 5

// Battery voltage divider input. GPIO34 is input-only and ADC1_CH6.
// Wiring: Battery+ -> R1 100k -> GPIO34 -> R2 100k -> GND.
#define BATTERY_ADC_PIN 34
#define BATTERY_ADC_MAX 4095
#define BATTERY_REF_MV 3300
#define BATTERY_DIVIDER 2.0f

// Motor PWM settings for ESP32 Arduino core v3 ledcAttach/ledcWrite API.
#define MOTOR_PWM_NORMAL 200
#define MOTOR_PWM_HOMING 150
#define MOTOR_PWM_FREQ 5000
#define MOTOR_PWM_RES 8

// Timed position model: position unit 0-100 maps to 0-100mm extension.
#define MOTOR_SPEED_MM_PER_MS 0.075f
#define MAX_POSITION_MM 100
#define POSITION_UNIT_TO_MM 1.0f

// Homing and safety.
#define HOMING_TIMEOUT_MS 3000
#define HOMING_EXTRA_MS 200
#define FAILSAFE_TIMEOUT_MS 2000
#define MIN_POSITION_CHANGE 3

// BLE UUIDs. Must match app/frontend/src/bleManager.ts exactly.
#define BLE_DEVICE_NAME "POSCHAIR_001"
#define SERVICE_UUID "a1b2c3d4-0001-4b5c-8d6e-1f2a3b4c5d6e"
#define COMMAND_CHAR_UUID "a1b2c3d4-0002-4b5c-8d6e-1f2a3b4c5d6e"
#define STATUS_CHAR_UUID "a1b2c3d4-0003-4b5c-8d6e-1f2a3b4c5d6e"

#define STATUS_INTERVAL_MS 1000

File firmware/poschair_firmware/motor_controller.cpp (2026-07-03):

#include "motor_controller.h"

void MotorController::begin() {
  pinMode(EN_PIN, OUTPUT);
  digitalWrite(EN_PIN, HIGH);

  for (int i = 0; i < NUM_MODULES; i++) {
    ledcAttach(RPWM_PINS[i], MOTOR_PWM_FREQ, MOTOR_PWM_RES);
    ledcAttach(LPWM_PINS[i], MOTOR_PWM_FREQ, MOTOR_PWM_RES);
    _stop(i);
    _currentPos[i] = 0;
    _targetPos[i] = 0;
    _state[i] = MotorState::IDLE;
  }

  Serial.println("[Motor] BTS7960 outputs initialised.");
}

void MotorController::homeAll() {
  Serial.println("[Motor] Homing all modules to fully retracted position...");
  _homingDone = false;

  for (int i = 0; i < NUM_MODULES; i++) {
    _state[i] = MotorState::HOMING;
    _driveIn(i, MOTOR_PWM_HOMING);
  }

  delay(HOMING_TIMEOUT_MS);

  for (int i = 0; i < NUM_MODULES; i++) {
    _brake(i);
  }
  delay(HOMING_EXTRA_MS);

  for (int i = 0; i < NUM_MODULES; i++) {
    _stop(i);
    _currentPos[i] = 0;
    _targetPos[i] = 0;
    _state[i] = MotorState::IDLE;
  }

  _homingDone = true;
  Serial.println("[Motor] Homing complete. All positions zeroed.");
}

void MotorController::setTarget(int idx, uint8_t position) {
  if (idx < 0 || idx >= NUM_MODULES) return;
  if (position > MAX_POSITION_MM) position = MAX_POSITION_MM;

  if (abs((int)position - (int)_targetPos[idx]) < MIN_POSITION_CHANGE) return;

  _targetPos[idx] = position;
  _moveDurationMs[idx] = _durationForDelta(_currentPos[idx], _targetPos[idx]);
  _moveStartMs[idx] = millis();

  if (_moveDurationMs[idx] == 0 || _currentPos[idx] == _targetPos[idx]) {
    _stop(idx);
    _currentPos[idx] = _targetPos[idx];
    _state[idx] = MotorState::IDLE;
    return;
  }

  if (_targetPos[idx] > _currentPos[idx]) {
    _state[idx] = MotorState::MOVING_OUT;
    _driveOut(idx, MOTOR_PWM_NORMAL);
  } else {
    _state[idx] = MotorState::MOVING_IN;
    _driveIn(idx, MOTOR_PWM_NORMAL);
  }
}

void MotorController::update() {
  const unsigned long now = millis();

  for (int i = 0; i < NUM_MODULES; i++) {
    if (_state[i] != MotorState::MOVING_OUT && _state[i] != MotorState::MOVING_IN) continue;

    const unsigned long elapsed = now - _moveStartMs[i];
    if (elapsed >= _moveDurationMs[i]) {
      _stop(i);
      _currentPos[i] = _targetPos[i];
      _state[i] = MotorState::IDLE;
    }
  }
}

uint8_t MotorController::getCurrentPosition(int idx) const {
  if (idx < 0 || idx >= NUM_MODULES) return 0;
  return _currentPos[idx];
}

bool MotorController::isAnyMoving() const {
  for (int i = 0; i < NUM_MODULES; i++) {
    if (_state[i] != MotorState::IDLE) return true;
  }
  return false;
}

void MotorController::stopAll() {
  for (int i = 0; i < NUM_MODULES; i++) {
    _stop(i);
    _targetPos[i] = _currentPos[i];
    _state[i] = MotorState::IDLE;
  }
}

void MotorController::_driveOut(int idx, uint8_t pwm) {
  ledcWrite(RPWM_PINS[idx], pwm);
  ledcWrite(LPWM_PINS[idx], 0);
}

void MotorController::_driveIn(int idx, uint8_t pwm) {
  ledcWrite(RPWM_PINS[idx], 0);
  ledcWrite(LPWM_PINS[idx], pwm);
}

void MotorController::_stop(int idx) {
  ledcWrite(RPWM_PINS[idx], 0);
  ledcWrite(LPWM_PINS[idx], 0);
}

void MotorController::_brake(int idx) {
  ledcWrite(RPWM_PINS[idx], 255);
  ledcWrite(LPWM_PINS[idx], 255);
}

unsigned long MotorController::_durationForDelta(uint8_t fromPos, uint8_t toPos) const {
  const float deltaMm = abs((int)toPos - (int)fromPos) * POSITION_UNIT_TO_MM;
  if (MOTOR_SPEED_MM_PER_MS <= 0.0f) return 0;
  return (unsigned long)(deltaMm / MOTOR_SPEED_MM_PER_MS);
}

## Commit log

2026-07-02 Scaffold and build PosChair posture corrector firmware and app
    [ble_manager.cpp, config.h, poschair_firmware.ino]
2026-07-02 Add hardware kinetic startup animation to ESP32-C3 firmware
2026-07-03 Upgrade PosChair to v3 motor actuator architecture
2026-07-06 Migrate firmware pinout to ESP32 DevKit V1
2026-07-06 Ignore local Arduino CLI tooling
2026-07-07 Add build-ready wiring diagrams
2026-07-08 Add interactive ESP32 bench test sketch
2026-07-08 Add automatic motor sequence test sketch
2026-07-08 final thingy
    [InnerTube.obj, InnerTube.stl, Middle1Tube.obj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]

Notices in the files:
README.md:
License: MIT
